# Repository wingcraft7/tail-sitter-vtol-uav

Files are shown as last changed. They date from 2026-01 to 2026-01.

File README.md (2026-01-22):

# Tail-Sitter VTOL UAV – Conceptual Design & Aerodynamic Analysis

The conceptual design and aerodynamic analysis of a flying-wing tail-sitter vertical takeoff and landing (VTOL) unmanned aerial vehicle (UAV) are presented in this repository. Aerodynamic efficiency and geometric simplicitymare the main goals of the project.

---

## Project Overview

The aircraft uses twin tractor propulsion, a blended center body, and a tailless flying-wing configuration. OpenVSP was used to develop the geometry parametrically. The VSPAERO panel-method solver was then used to estimate parasite drag and perform aerodynamic analysis.

---

## Key Design Features

- Tail-sitter VTOL configuration
- Flying-wing planform with blended center body
- Aspect ratio = 9, wingspan = 1.4 m
- NACA 4415 root airfoil, NACA 0012 tip airfoil
- −2° linear washout from root to tip
- Elevons for combined pitch and roll control
- Twin wing-mounted tractor propulsion

---

## Aerodynamic Analysis Summary

- Parasite drag build-up performed at 100 km/h, sea level
- Zero-lift drag coefficient: **CD₀ ≈ 0.018** (including 7% excrescence)
- VSPAERO angle-of-attack sweep: −4° to +14°
- Lift coefficient: **CL ≈ 0.85 at 10° AoA**
- Smooth drag rise and stable pitching moment behavior
- Peak lift-to-drag ratio at moderate angles of attack

---

## Tools Used

- OpenVSP (geometry modeling and parasite drag estimation)
- VSPAERO (panel-method aerodynamic analysis)
- LaTeX (technical documentation)

---

## Repository Contents

- `report/` – Final research-style technical report (PDF)
- `geometry/` – OpenVSP (.vsp3) aircraft geometry file
- `figures/` – Key geometry and aerodynamic result figures
- `analysis_notes/` – Analysis assumptions and solver settings

---

## Limitations and Future Work

This work is limited to conceptual level inviscid aerodynamic analysis. Future research would focus on flight dynamics and control analysis, propulsion sizing, CFD simulations with viscous effects, and structural finite element analysis.

**Note** - An RC transmitter is not included in the BOM, as it will be sourced from my college equipment for testing.

---

## Author

Pushkal Garg  
B.Tech Mechanical Engineering  
IIT Ropar

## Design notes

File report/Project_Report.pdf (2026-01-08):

# Conceptual Design and Preliminary Aerodynamic Analysis of a Tail-Sitter Flying-Wing VTOL UAV

### Pushkal Garg

### Department of Mechanical Engineering

### Indian Institute of Technology Ropar

### Contents

1 Introduction | 2
2 Mission Requirements and Design Objectives | 2
3 Configuration Selection | 3
4 Wing Geometry Design | 4
5 Blended Center Body Implementation | 7
6 Control Surfaces | 7
7 Propulsion System Modeling | 8
8 Aerodynamic Analysis Using OpenVSP | 8
9 Structural Analysis Considerations | 14
10 Conclusions | 15
11 Future Work | 15

Abstract
This report presents the conceptual design, geometric modeling, and preliminary aerodynamic analysis of a tail-sitter vertical takeoff and landing (VTOL) unmanned aerial vehicle (UAV). The project aims to bridge the gap between efficient fixed-wing cruise and rotary-wing hovering capabilities. A tailless flying-wing configuration with twin tractor propulsion was selected to minimize drag and structural complexity. Geometric modeling was performed using OpenVSP, incorporating a blended center body and specific washout to ensure stability. Preliminary aerodynamic analysis using VSPAERO’s panel method indicated a zero-lift drag coefficient (CD0) of approximately 0.017, validating the aerodynamic cleanliness of the design. The results demonstrate that the proposed configuration offers a viable solution for missions requiring both endurance and vertical mobility, suitable for further structural optimization and prototype development.

### 1 Introduction

Vertical takeoff and landing (VTOL) unmanned aerial vehicles (UAVs) have become increasingly important for applications requiring operation in confined or infrastructurelimited environments. While multirotor UAVs provide excellent hover and low-speed maneuverability, their endurance and range are limited by poor aerodynamic efficiency in forward flight. Fixed-wing UAVs, in contrast, offer superior aerodynamic performance but require runways or launch and recovery systems.

Hybrid VTOL concepts aim to combine the advantages of both configurations. Among these, the tail-sitter configuration is particularly attractive due to its mechanical simplicity. By rotating the entire aircraft between vertical and horizontal flight modes, tail-sitters eliminate the need for tilting propulsion systems or auxiliary lifting rotors. However, this simplicity places stringent requirements on aerodynamic efficiency, stability, and control, especially for tailless configurations.

This report presents the conceptual design and preliminary aerodynamic analysis of a tail-sitter UAV based on a flying-wing configuration. The geometry was developed parametrically using OpenVSP, followed by preliminary aerodynamic evaluation using the VSPAERO solver. The primary objective is to assess the feasibility of the proposed configuration at the conceptual design stage and establish a foundation for further structural and high-fidelity aerodynamic studies.

### 2 Mission Requirements and Design Objectives

### 2.1 Primary Objectives

- VTOL Capability: The vehicle must be capable of taking off and landing vertically from unprepared terrain, utilizing a tail-sitter configuration to minimize mechanical complexity.
- Efficient Cruise: The platform must achieve efficient forward-flight performance at low subsonic speeds, surpassing the endurance of comparable multi-rotor systems.
- Structural Simplicity: The design should minimize moving parts (e.g., no tilting mechanisms) to ensure robustness and suitability for lightweight manufacturing techniques such as composite molding or foam cutting.

- Control Authority: The design must provide adequate control authority in both hover (via differential thrust and slipstream effects) and forward flight (via aerodynamic surfaces) without conventional tail surfaces.

### 2.2 Performance constraints

A representative cruise condition of approximately 100 km/h at sea level was selected for aerodynamic evaluation. The design prioritizes low drag, sufficient internal volume for avionics and payload, and compatibility with student-level numerical analysis tools.

### 3 Configuration Selection

Several VTOL configurations were evaluated, including tilt-wings, separate lift-thrust configurations, and tail-sitters. A tailless flying-wing tail-sitter was selected for the following reasons:

1. Aerodynamic Efficiency: The flying wing maximizes the lifting surface area relative to wetted area, reducing parasite drag.
2. Structural Efficiency: The absence of a long fuselage tail boom reduces bending moments and overall structural weight.
3. Mechanization: Unlike tilt-rotors, the motors are rigidly mounted. This reduces failure points and simplifies the autopilot mixing logic.

Twin wing-mounted tractor propellers were chosen to provide symmetric thrust. This arrangement allows for differential thrust to control yaw in hover and roll in forward flight, while also ensuring the control surfaces (elevons) remain in the propeller slipstream for effectiveness at zero forward airspeed.

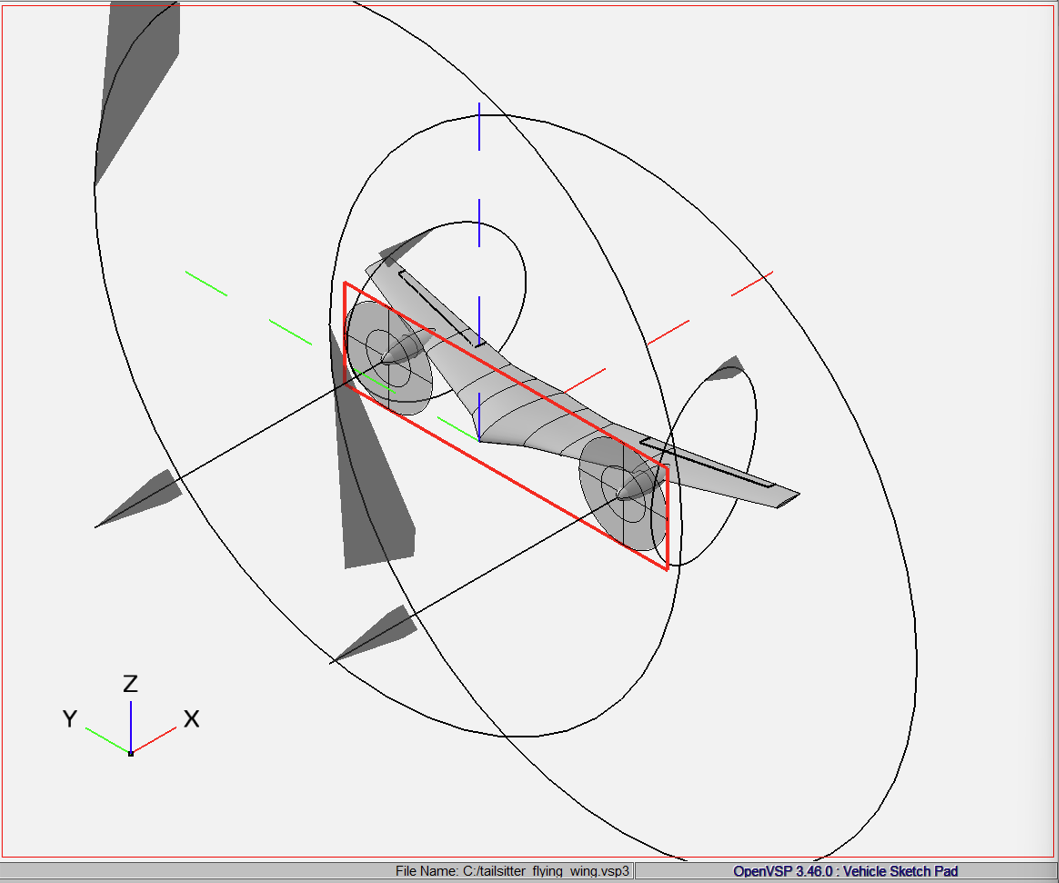
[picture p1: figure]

Figure 1: Final OpenVSP geometry of the tail-sitter UAV with twin tractor propulsion.

### 4 Wing Geometry Design

The wing is the primary lifting surface and the most critical component of the design. Its geometry was iteratively refined in OpenVSP.

### 4.1 Planform Selection

The wing was designed as a moderately high aspect-ratio flying wing.

- Aspect Ratio (≈ 9): A higher aspect ratio reduces induced drag, which is the dominant drag component during the low-speed transition phase and loiter.
- Sweep: Moderate leading-edge sweep was applied. This improves longitudinal stability by shifting the aerodynamic center rearward, allowing for a more flexible center of gravity (CG) placement.
- Taper: A taper ratio of less than 1.0 was applied to approximate an elliptical lift distribution, thereby minimizing induced drag and reducing the structural weight of the outboard wing sections.

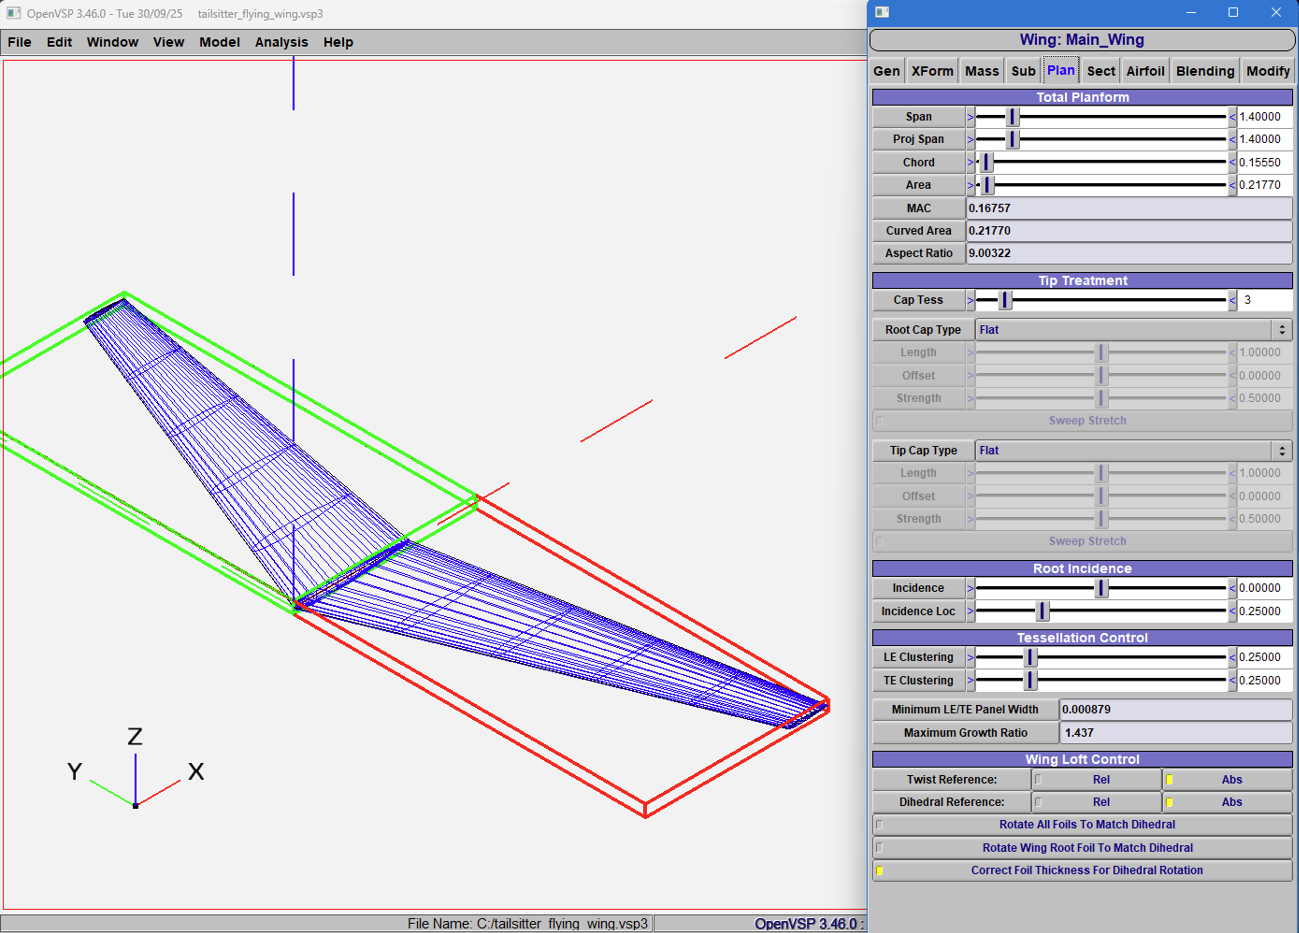
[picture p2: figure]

Figure 2: Wing planform definition in OpenVSP showing span, aspect ratio, sweep, and taper.

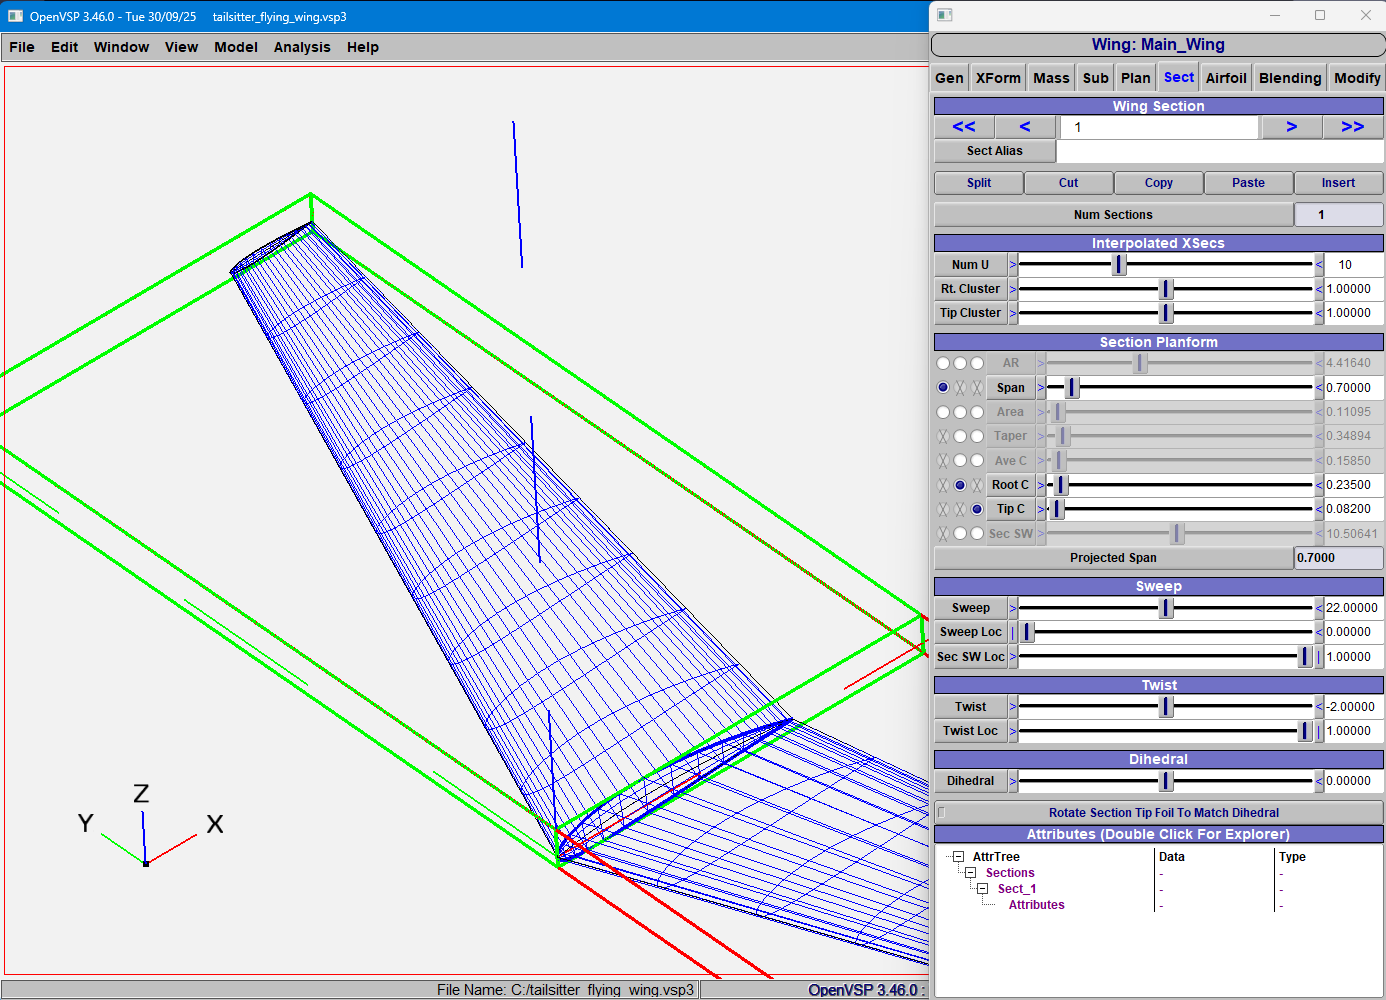
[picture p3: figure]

Figure 3: Wing planform definition in OpenVSP showing Root Chord and Tip Chord

### 4.2 Airfoil Selection

To balance conflicting requirements between the root structural depth and tip stall characteristics, aerodynamic lofting was used between two distinct airfoils:

Table 1: Airfoil Selection and Rationale
Location Airfoil | Rationale
Root | NACA 4415 15% thickness provides volume for spars
and batteries; high CL,max for lift.
Tip | NACA 0012 12% thickness; Symmetric section ensures
zero pitching moment at the tips.

Airfoil selection was driven by the need to provide high lift capability at low Reynolds numbers while maintaining acceptable pitching moment characteristics and structural stiffness. At the wing root, a NACA 4415 airfoil with a thickness-to-chord ratio of 15% was selected. The cambered profile provides enhanced lift at moderate angles of attack, which is beneficial during transition and forward flight, while the increased thickness allows space for internal spars and avionics.

At the wing tip, a symmetric NACA 0012 airfoil with a thickness-to-chord ratio of 12% was selected. The symmetric airfoil reduces adverse pitching moments and delays tip stall, which is particularly important for tailless flying-wing configurations where tip stall can lead to abrupt loss of control. A smooth S-curve interpolation was employed between the root and tip airfoils to ensure gradual variation of camber and thickness along the span.

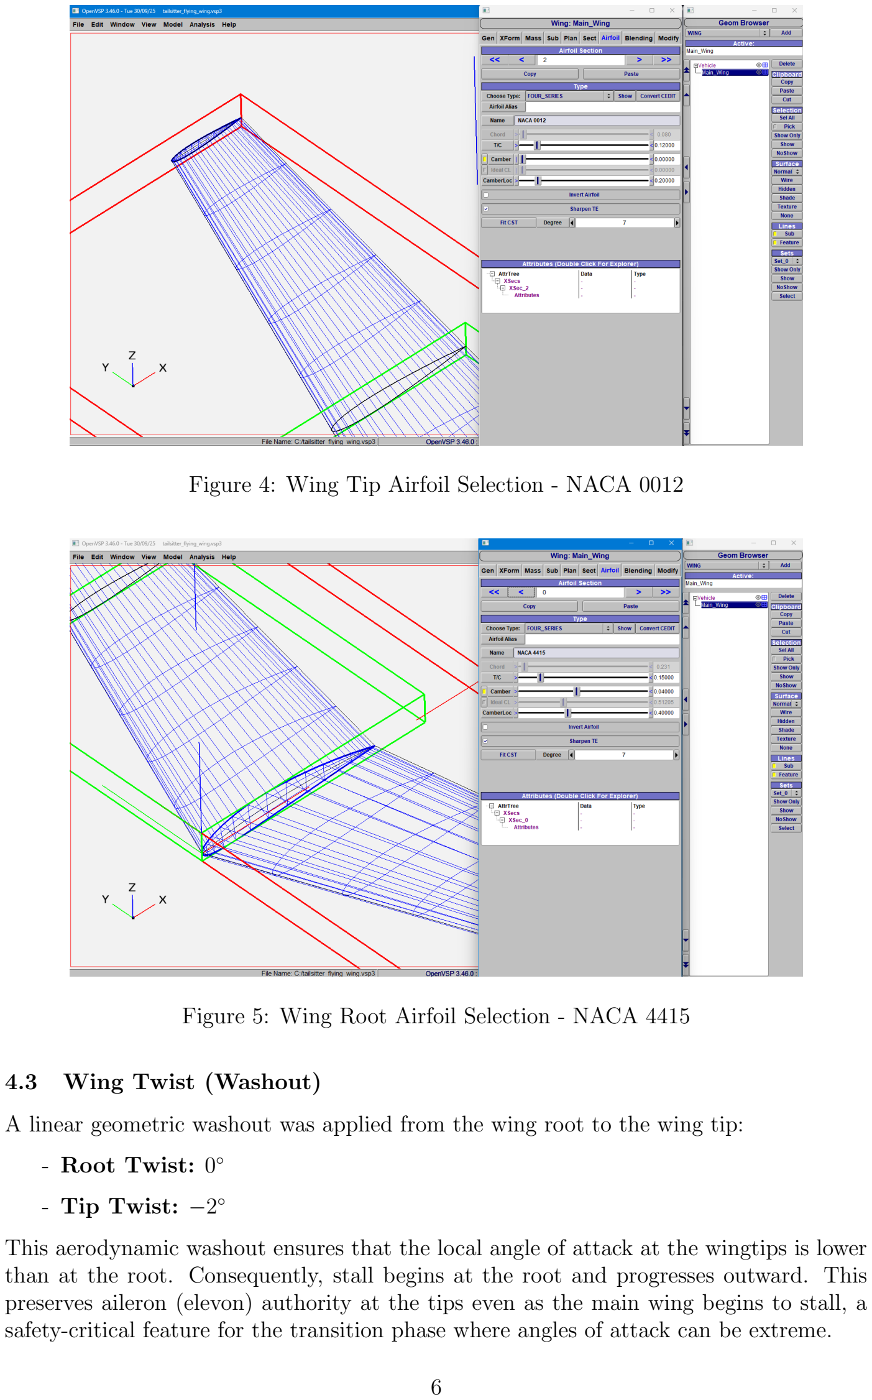
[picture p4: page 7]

Figure 4: Wing Tip Airfoil Selection - NACA 0012

Figure 5: Wing Root Airfoil Selection - NACA 4415

### 4.3 Wing Twist (Washout)

A linear geometric washout was applied from the wing root to the wing tip:

- Root Twist: 0

◦

- Tip Twist: −2

◦

This aerodynamic washout ensures that the local angle of attack at the wingtips is lower than at the root. Consequently, stall begins at the root and progresses outward. This preserves aileron (elevon) authority at the tips even as the main wing begins to stall, a safety-critical feature for the transition phase where angles of attack can be extreme.

### 5 Blended Center Body Implementation

Rather than introducing a separate fuselage, a blended center-body configuration was implemented by locally increasing the thickness of the central wing sections. Multiple wing sections were used to smoothly transition from the thickened center region to the baseline wing geometry. The maximum thickness in the center region was limited to approximately 18–20% of the local chord to avoid excessive aerodynamic penalties.

In OpenVSP, this was achieved by using multiple cross-sections with specific skinning controls to ensure continuity (C2 continuity). This blended region houses the flight controller, battery, and avionics. This design choice reduces the ”wetted area” compared to a pod-and-boom configuration, directly contributing to the low drag coefficient observed in analysis.

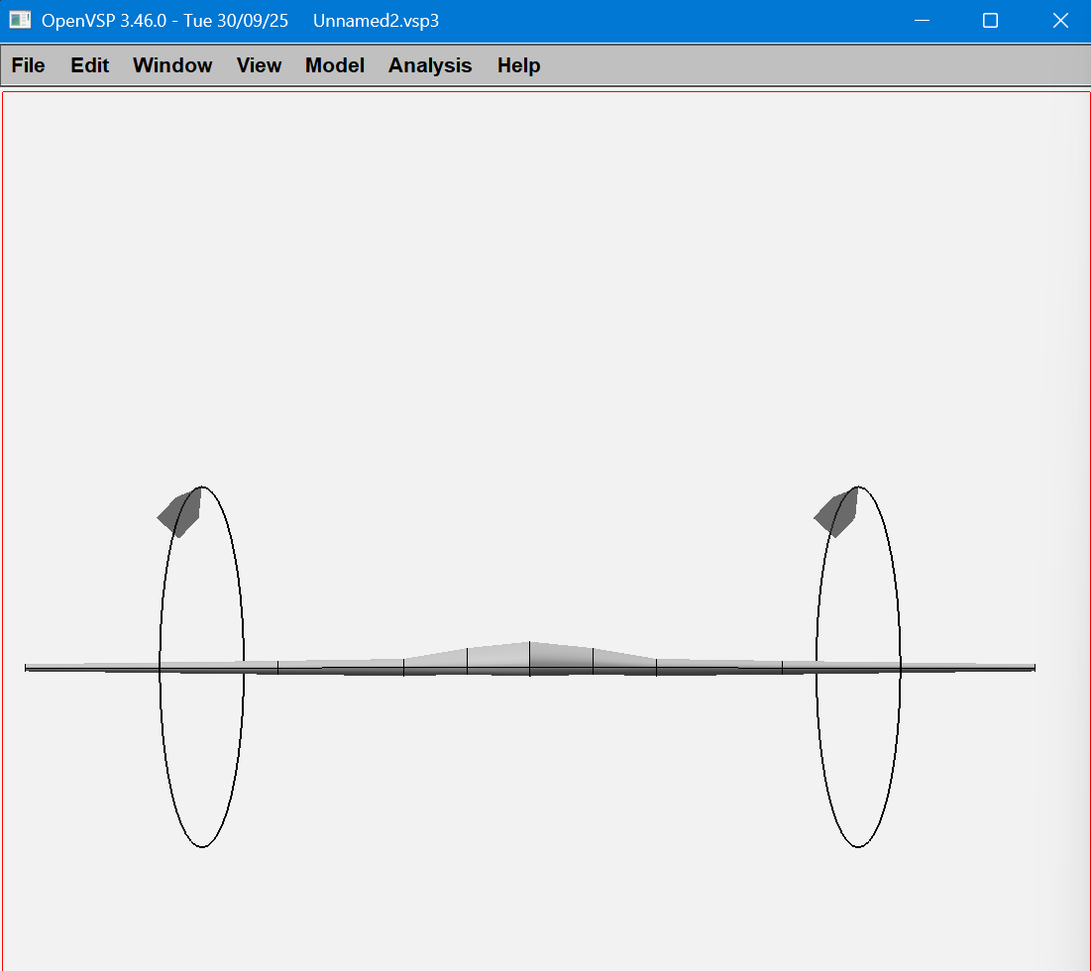
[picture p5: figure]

Figure 6: Blended center-body configuration achieved by locally increasing the thickness of the central wing sections.

### 6 Control Surfaces

The aircraft utilizes full-span control surfaces, specifically elevons, located on the outboard wing sections.

- Function: They mix pitch (elevator) and roll (aileron) control.
- Sizing: The elevons span approximately 60% to 80% of the semi-span with a chord ratio of 25%.
- Placement: They are positioned outboard to maximize the moment arm for roll control, but sufficiently immersed in the propeller slipstream to allow for vectoring of the thrust during hover.

The use of elevons is standard practice for tailless flying-wing configurations and provides sufficient control authority during both forward flight and transition phases.

### 7 Propulsion System Modeling

Twin wing-mounted tractor propulsion units were modeled using streamlined ellipsoidal nacelles to represent the motor housing and spinner. Each nacelle had a characteristic length of approximately 0.12 m and a maximum diameter of approximately 0.05 m. The nacelles were positioned near 25–35% of the semi-span to balance thrust distribution and structural considerations.

Propellers were represented using actuator disks with a diameter of approximately 0.27 m. This simplified representation avoids excessive geometric complexity while clearly defining thrust locations for aerodynamic and structural analysis.

The twin tractor configuration provides redundancy. In the event of a single motor failure, the aircraft can potentially enter a flat spin recovery or controlled descent, which is impossible with a single-engine tail-sitter.

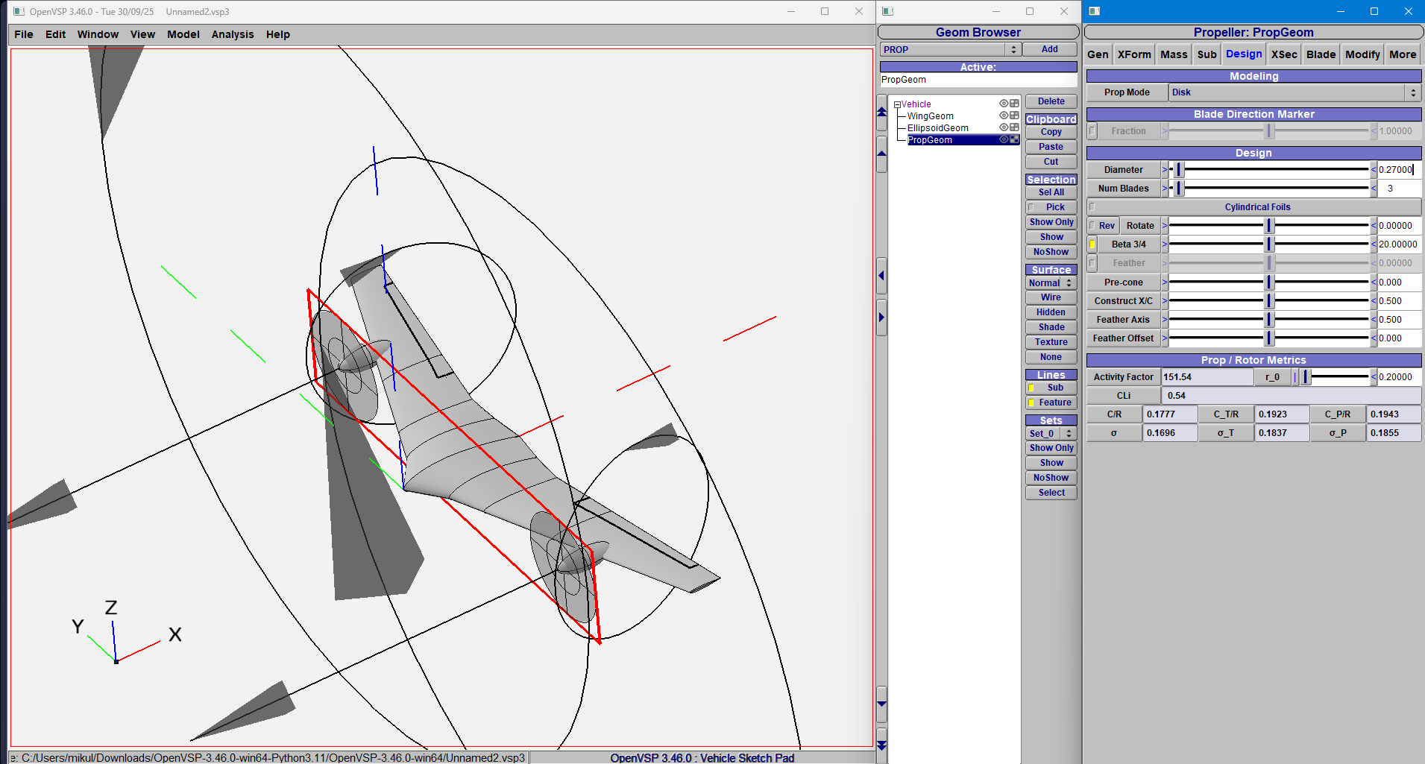
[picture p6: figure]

Figure 7: Ellipsoidal motor nacelles with actuator disk representation of the propellers in a twin tractor configuration.

### 8 Aerodynamic Analysis Using OpenVSP

This section documents the methodology, assumptions, solver settings, and results of the preliminary aerodynamic analysis conducted using OpenVSP. Two complementary approaches were employed:

- Parasite drag build-up analysis
- Panel-method aerodynamic analysis using VSPAERO.

Together, these methods provide a consistent conceptual-level assessment of the aerodynamic performance of the proposed tail-sitter UAV.

### 8.1 Parasite Drag Estimation

### 8.1.1 Methodology

Parasite drag was estimated using the built-in drag build-up method available in Open-VSP. This approach computes the zero-lift drag coefficient by summing contributions from skin-friction drag and form drag based on component wetted areas and empirical correlations. While this method does not capture induced drag or unsteady flow effects, it is widely used for conceptual design studies to obtain first-order drag estimates.

The analysis was conducted for a representative forward-flight cruise condition corresponding to low subsonic operation, consistent with the intended mission profile of the UAV.

### 8.1.2 Flight Condition and Atmospheric Assumptions

The following flight conditions were used for parasite drag estimation:

- True airspeed: 100 km/h (27.8 m/s)
- Altitude: 0 m (sea level)
- Mach number: 0.08
- Atmospheric model: Standard sea-level conditions

This flight condition was selected to ensure that compressibility effects are negligible and that the Reynolds number regime is representative of small UAV operation.

### 8.1.3 Reference Geometry Parameters

The reference quantities used in the drag calculation were derived from the OpenVSP geometry:

- Wing planform area: 0.22–0.24 m²
- Wetted area: Automatically computed by OpenVSP
- Reference length: Mean Aerodynamic Chord (MAC)
- MAC value: 0.17 m

The mean aerodynamic chord was selected as the reference length because it provides a physically meaningful scale for non-dimensional aerodynamic coefficients for tapered flying-wing configurations.

### 8.1.4 Excrescence Drag Modeling

To account for real-world drag sources not explicitly modeled in the geometry, an excrescence drag increment was applied. These sources include:

- Surface roughness
- Control surface hinge gaps
- Manufacturing tolerances
- Small protuberances and junction imperfections

An excrescence increment of 7% was applied to the baseline parasite drag coefficient. This value is representative of a clean, small-scale UAV configuration and is commonly adopted in conceptual-level drag build-up analyses.

### 8.1.5 Parasite Drag Result

The resulting zero-lift drag coefficient including excrescence effects was found to be:

CD0 ≈ 0.018 | (1)

This implies a highly efficient airframe. For comparison, a standard Cessna 172 has a CD0 of roughly 0.027, and many foam UAVs exceed 0.03. This low drag value suggests the blended body and clean wing design were successful strategies.

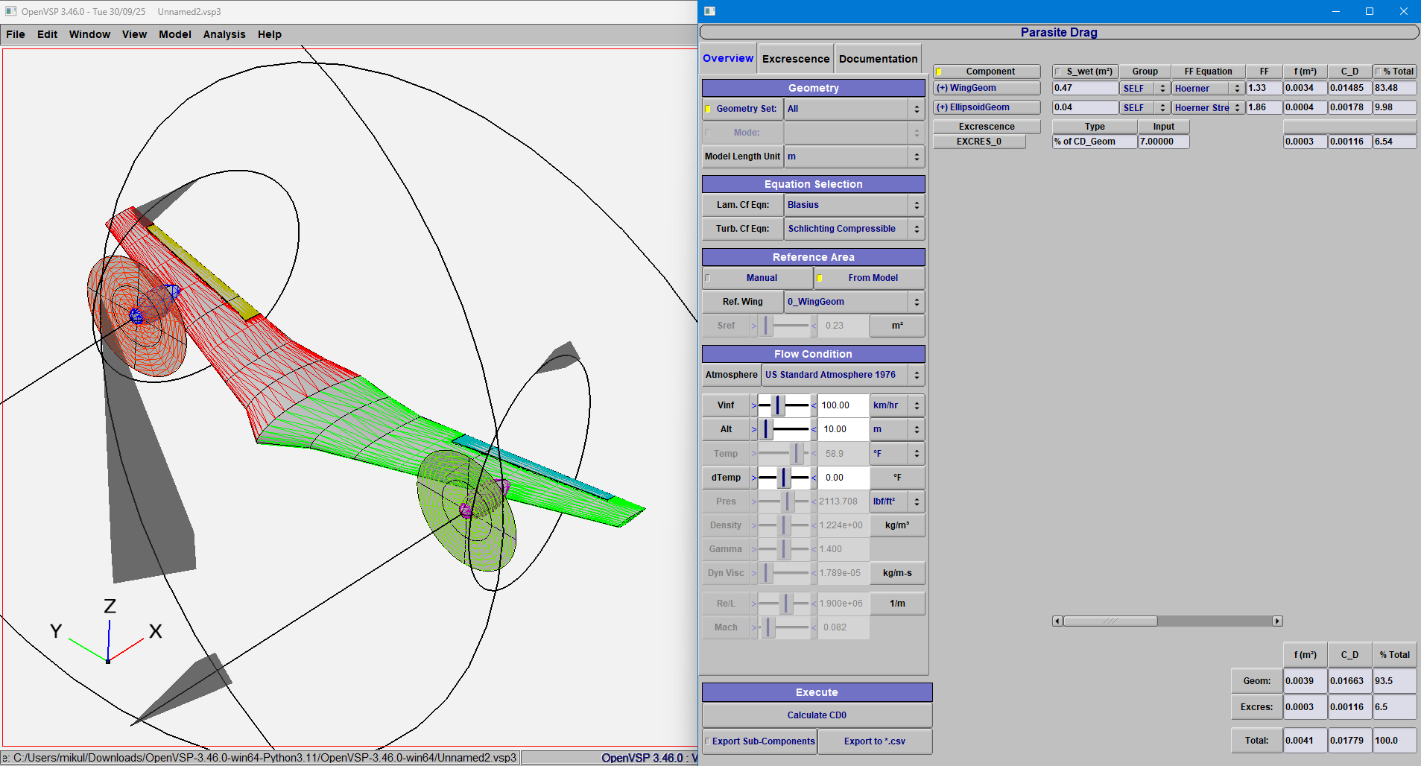
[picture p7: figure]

Figure 8: Parasite drag estimation using the OpenVSP drag build-up method at a cruise speed of 100 km/h with excrescence effects included.

### 8.2 Aerodynamic Analysis Using VSPAERO

### 8.2.1 Solver Description

VSPAERO is a vortex-lattice / panel-method solver integrated within OpenVSP. It computes aerodynamic forces and moments under the assumption of inviscid, irrotational flow. While viscous effects and flow separation are not explicitly captured, VSPAERO is well suited for evaluating lift, induced drag, and pitching moment trends within the pre-stall flight regime at the conceptual design stage.

### 8.2.2 Geometry and Symmetry Assumptions

The full aircraft geometry was modeled in OpenVSP, including the blended center body, elevons, motor nacelles, and propeller disks (represented geometrically only). No geometric symmetry was imposed in the solver to avoid inconsistencies between reference area definitions and force integration.

- Symmetry: Disabled
- Half-model assumptions: Not used

This approach ensures that all aerodynamic coefficients are computed based on the full aircraft geometry.

### 8.2.3 Reference Quantities and Coordinate System

To ensure physically meaningful aerodynamic coefficients, reference quantities were manually specified:

- Reference area: Wing planform area (≈0.23 m²)
- Reference span: ≈1.4m
- Reference span: ≈1.4m
- Reference chord: Mean Aerodynamic Chord (MAC ≈ 0.17 m)

The body-fixed coordinate system was defined such that:

- X-axis: Aligned with the forward-flight direction
- Z-axis: Positive upward (lift direction)
- Y-axis: Lateral direction

### 8.2.4 Angle-of-Attack Sweep Parameters

Angle-of-attack sweeps were conducted to evaluate lift, drag, and pitching moment behavior across the pre-stall flight envelope.

The sweep parameters were:

- Angle-of-attack range: 4° to +14°
- Increment: 2°
- Flight speed: 25 m/s
- Altitude: Sea level

This range captures negative-lift conditions, cruise operation, and high-lift operation while remaining within the validity limits of panel-method analysis.

Lift and drag were projected along the Z and X axes, respectively. This definition is particularly important for tail-sitter configurations, where the aircraft orientation differs between hover and forward flight.

### 8.2.5 Airfoil Interpolation and Numerical Settings

To ensure smooth geometric variation and numerical stability:

- Airfoil interpolation: S-curve
- Reference chord definition: MAC (not CAVE)

- Wake modeling: Default steady wake
- Solver type: Steady-state

The S-curve interpolation ensures gradual variation of thickness and camber between the root (NACA 4415) and tip (NACA 0012) airfoils, which is particularly important given the locally thickened center-body region.

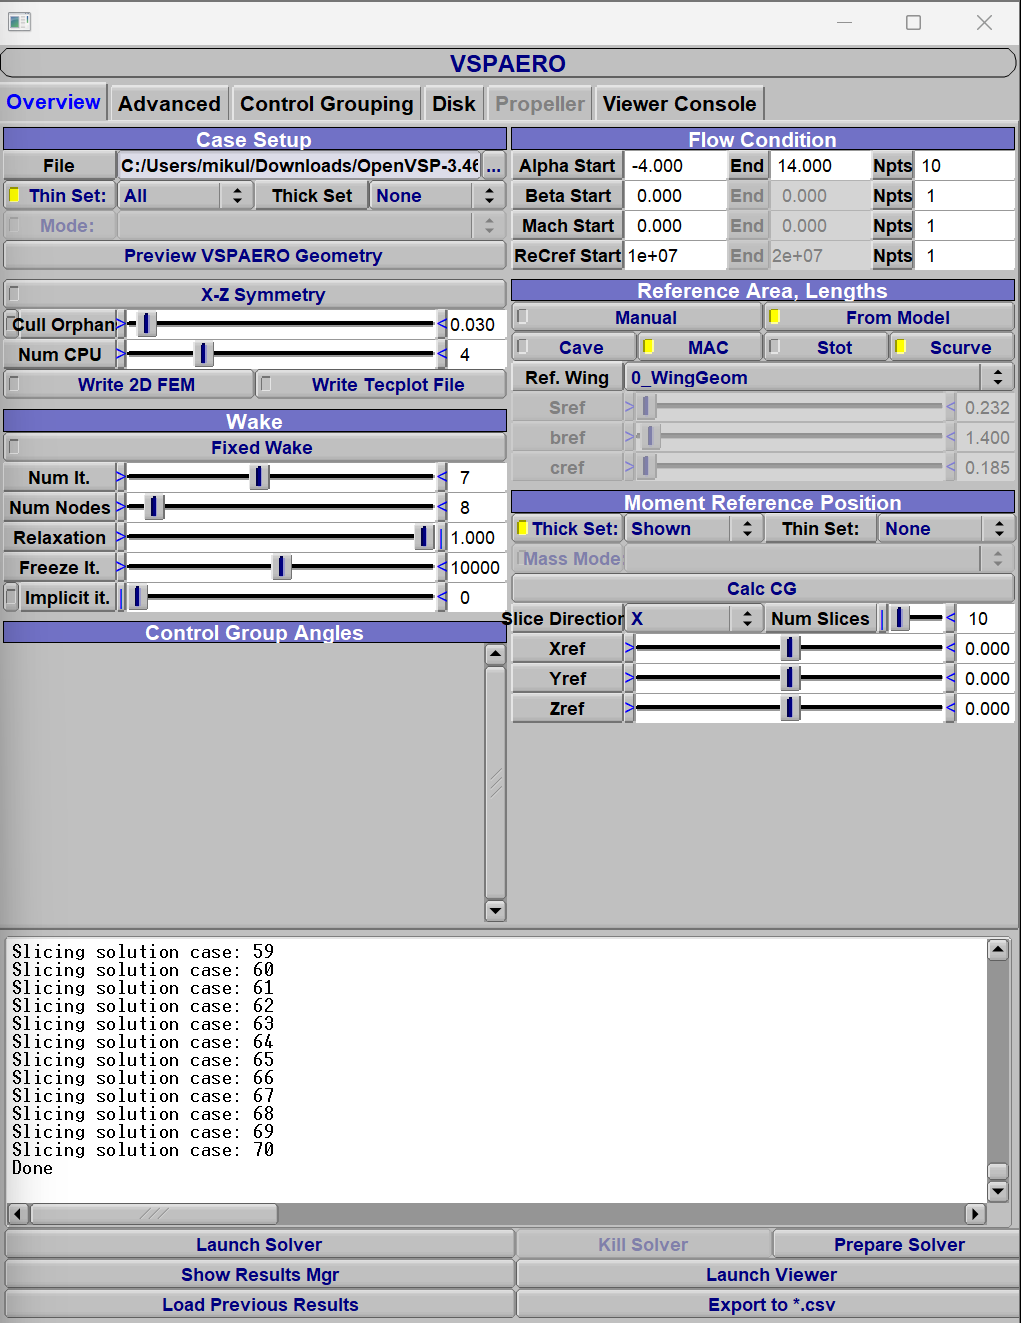
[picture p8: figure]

Figure 9: Parameters used for Aerodynamic Analysis

### 8.3 Aerodynamic Results and Discussion

### 8.3.1 Lift Characteristics

The lift coefficient exhibited an approximately linear variation with angle of attack within the analyzed range. At an angle of attack of 10°, the aircraft produced a lift coefficient of approximately:
CL ≈ 0.85 | (2)

This value is consistent with expectations for a moderately cambered flying-wing configuration operating at low Reynolds numbers. The applied washout and airfoil selection contribute to maintaining lift generation without excessive pitching moment.

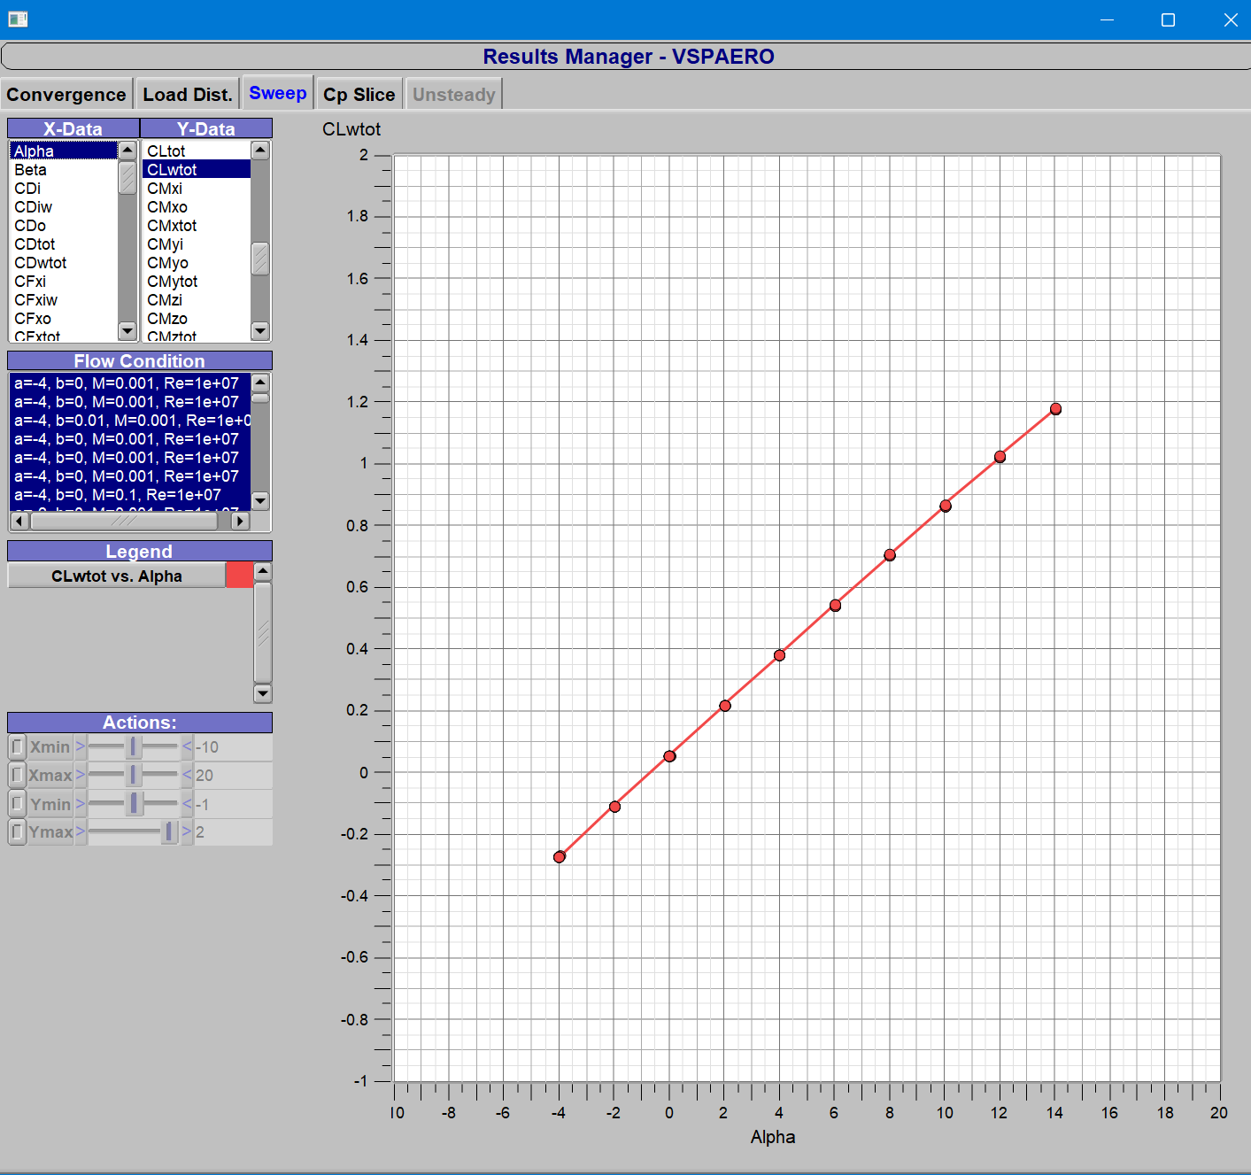
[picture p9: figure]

Figure 10: Lift coefficient variation with angle of attack

### 8.3.2 Drag Characteristics

The drag coefficient increased smoothly with angle of attack, reflecting the expected rise in induced drag as lift increases. When combined with the previously estimated parasite drag, the total drag behavior indicates good aerodynamic efficiency in the cruise and high-lift regimes.

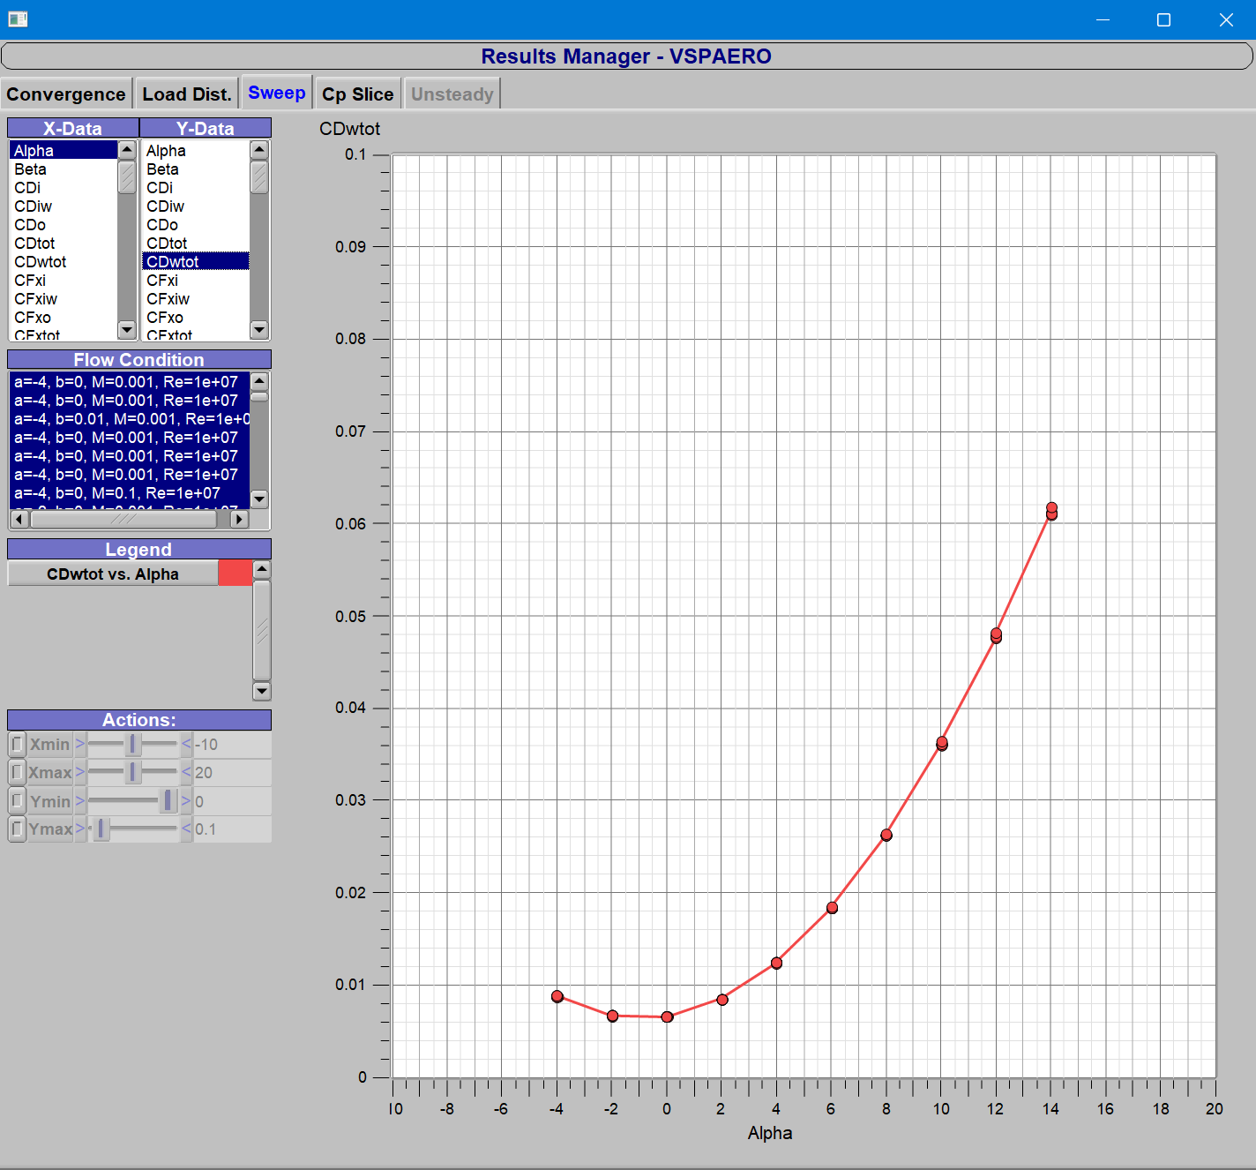
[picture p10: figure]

Figure 11: Drag coefficient variation with angle of attack

### 8.3.3 Aerodynamic Efficiency

The lift-to-drag ratio exhibited a clear maximum at moderate angles of attack, corresponding to the most aerodynamically efficient operating condition. This angle of attack was selected as the representative cruise condition for performance discussion.

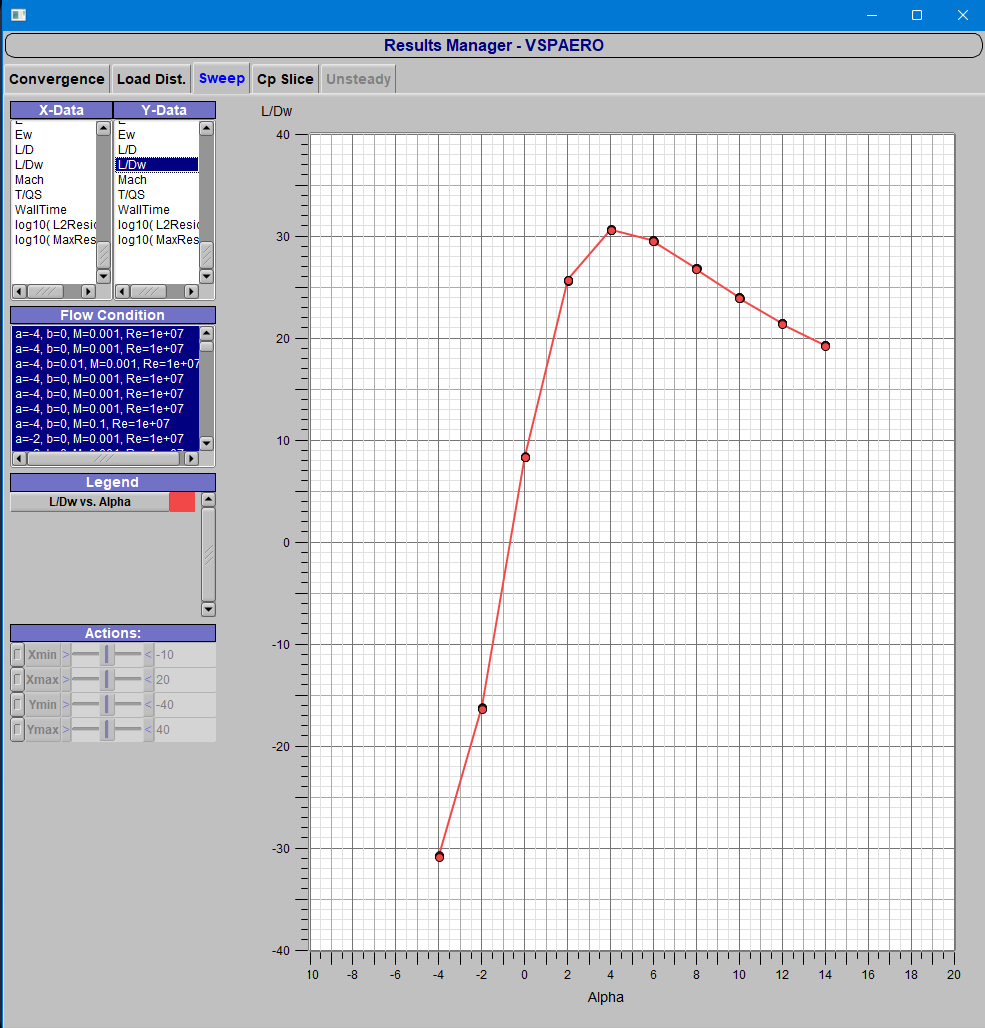
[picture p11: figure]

Figure 12: L/D ratio variation with angle of attack

### 8.4 Limitations of the Analysis

It is important to note that the aerodynamic analysis presented here is subject to the limitations of the employed methods. VSPAERO does not model viscous effects, flow separation, or propeller–airframe interaction. Consequently, the results are intended for conceptual design validation rather than high-fidelity prediction. These limitations motivate future studies using Reynolds-averaged Navier–Stokes (RANS) CFD and experimental validation.

### 9 Structural Analysis Considerations

Although the primary focus of this report is aerodynamic design, the geometry was created with structural constraints in mind.

- Load Paths: The straight leading edge of the internal structural box (spar location) allows for a continuous carbon fiber tube or I-beam spar.
- Material: The volume analysis from OpenVSP supports the use of expanded polypropylene (EPP) foam for the wing core, reinforced with carbon fiber spars, a standard method for lightweight UAVs.

- FEM Compatibility: The OpenVSP model was exported as an STL and STEP file, which verified that the geometry is ”watertight” and suitable for meshing in Finite Element Analysis (FEA) software for future stress testing.

### 10 Conclusions

A conceptual design and preliminary aerodynamic analysis of a tail-sitter VTOL UAV based on a tailless flying-wing configuration was performed using OpenVSP and the VSPAERO panel-method solver. The aircraft geometry was developed parametrically, enabling systematic evaluation of wing planform parameters, airfoil selection, twist distribution, control surface integration, and propulsion layout.

The final configuration features a moderately high aspect ratio wing of approximately 9, with a wingspan of about 1.4 m and a wing planform area of approximately 0.22– 0.24 m²
. A cambered NACA 4415 airfoil with a thickness-to-chord ratio of 15% was selected at the wing root to enhance lift generation and structural stiffness, while a symmetric NACA 0012 airfoil with a thickness-to-chord ratio of 12% was employed at the wing tip to improve stall behavior and reduce adverse pitching moments. A linear geometric washout of −2

◦
from root to tip was applied to delay tip stall and improve controllability.

Parasite drag analysis conducted at a representative cruise speed of 100 km/h and sea-level conditions yielded a zero-lift drag coefficient of approximately CD0 ≈ 0.018, including a 7% excrescence increment. VSPAERO analysis over an angle-of-attack range of −4

◦
to +14◦ demonstrated near-linear lift characteristics within the pre-stall regime, with a lift coefficient of approximately CL ≈ 0.85 at 10◦ angle of attack. The drag coefficient increased smoothly with angle of attack, and the lift-to-drag ratio reached a maximum at moderate angles of attack, indicating an aerodynamically efficient cruise condition.

Overall, the results indicate that the proposed tail-sitter flying-wing UAV can achieve favorable aerodynamic performance while maintaining structural and mechanical simplicity. The developed configuration and analysis framework provide a solid foundation for subsequent structural analysis, higher-fidelity CFD studies, and flight dynamics and control investigations.

### 11 Future Work

To advance this project to a flight-ready prototype, the following steps are proposed:

1. CFD Analysis: Perform RANS (Reynolds-Averaged Navier-Stokes) CFD simulations to analyze high-angle-of-attack behavior (post-stall) during the transition phase, which VSPAERO cannot accurately predict.
2. Structural Sizing: Detailed FEM analysis to size the main spar for the high bending moments experienced during a 3G pull-up maneuver.
3. Propulsion Testing: Static thrust stand testing of selected motor-propeller combinations to validate efficiency assumptions.
4. Control Law Development: Simulation of the transition maneuver (hover to forward flight) to tune PID gains for the flight controller.

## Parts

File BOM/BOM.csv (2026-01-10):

Item | Description | Unit Price (INR) | Quantity | Total Price | Total Price (USD)
BLDC Motor | DYS D3548-5 900 KV BLDC Motor | 2050 | 2 | 4100 | 45
Flight Controller | Pixhawk 2.4.8 Drone Flight Controller PX4 32 Bit Autopilot | 6456 | 1 | 6456 | 71.5
Pixhawk Power Module | APM/Pixhawk Power Module Output BEC 3A XT60 Connector 28V 90A | 582 | 1 | 582 | 6.5
GPS Module | NEO-M8N (Ready To SKY) GPS Module with Compass for APM with extra connector for Pixhawk | 1956 | 1 | 1956 | 22
ESC | Readytosky 80A ESC 2-6S Brushless ESC Speed Controller for RC Drone | 1935 | 2 | 3870 | 43
Carbon Fibre Rod | Pultruded Carbon Fibre Rod (Solid) 0.8mm * 1000mm (Pack of 2) | 534 | 1 | 534 | 6
Propellors | Counter Rotating Carbon Fiber Propellers 1555 (CW+CCW) | 864 | 1 | 864 | 10
LiPo Battery | GenX 14.8V 4S 5200mAh 40C / 80C Premium Lipo Lithium Polymer Battery | 3225 | 1 | 3225 | 36
 |  |  |  | Total Sum (USD)= | 240

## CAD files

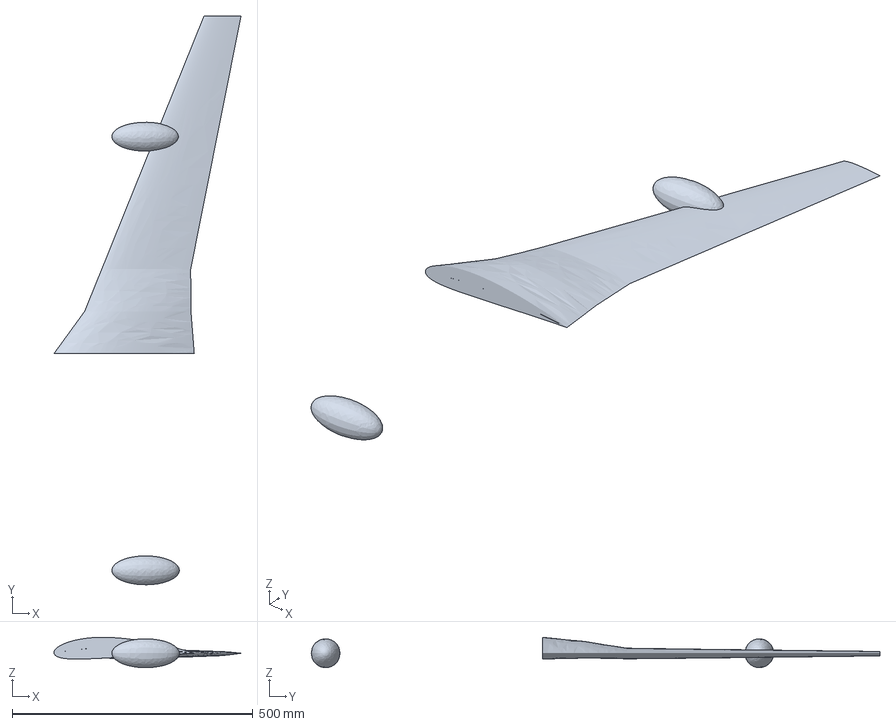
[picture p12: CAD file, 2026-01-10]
geometry/vtol_uav_stp9.stp
388.1 x 1180.0 x 63.1 mm

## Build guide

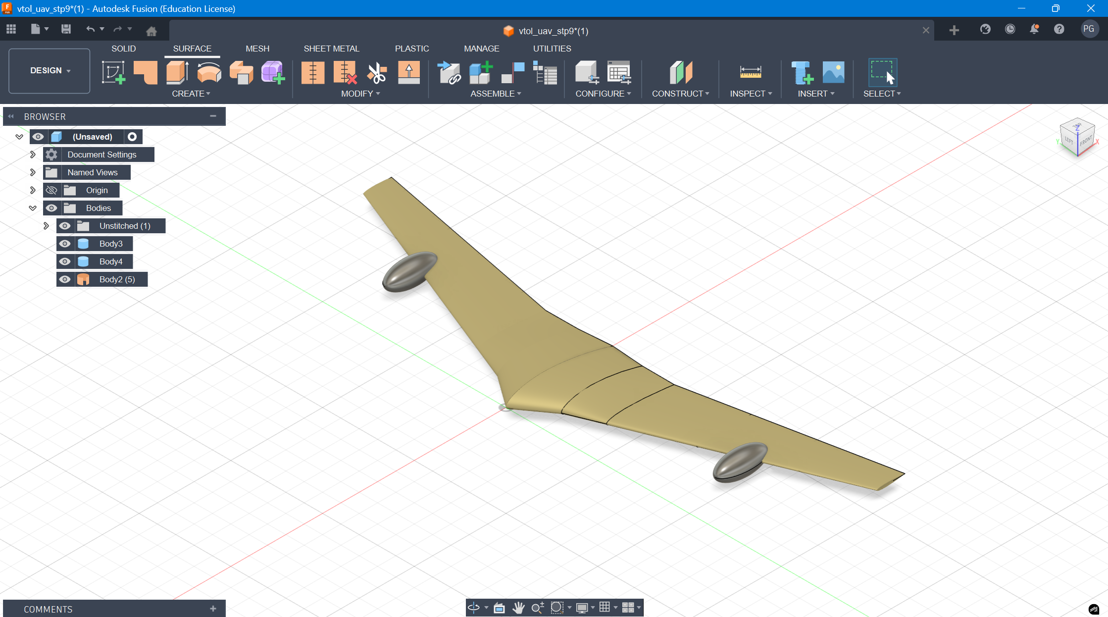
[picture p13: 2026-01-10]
figures/step_preview.png
